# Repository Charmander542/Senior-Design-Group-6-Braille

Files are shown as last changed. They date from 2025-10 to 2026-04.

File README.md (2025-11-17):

# Senior Design Group 6 - Braille Project

Welcome to the EC463 Senior Design Group 6 Braille project repository.

Main Google Doc before README migration: https://docs.google.com/document/d/1c1Lonarr0yz-ggmuZfPKdth9k53kwFiAMk2oVoeEsT8/edit?usp=sharing

## Project Structure

### 📁 `electrical/`
Contains hardware-related files including:
- **driver.cpp**: Driver code for hardware control
- **pcb/**: PCB design files
  - `conductors/`: Braille cell conductor board designs (KiCad files)
  - `controller/`: Braille cell controller board designs (KiCad files)
  - `devboard/`: Development board schematics

### 📚 `braille_converter/`
A Python library for converting text to 6-dot braille representation.

**Features:**
- ✨ Convert text to Unicode braille characters
- 📁 Convert entire text files to braille
- 🔍 Detailed character-by-character analysis
- 📊 Visual dot pattern representation
- 🎯 Full support for letters, numbers, punctuation, and symbols

**Quick Start:**
```python
from braille_converter import text_to_braille

text = "Hello World!"
braille = text_to_braille(text)
print(braille)  # Output: ⠠⠓⠑⠇⠇⠕⠀⠠⠺⠕⠗⠇⠙⠖
```

**Documentation:**
- [Full README](braille_converter/README.md) - Complete API documentation
- [Quick Start Guide](braille_converter/QUICKSTART.md) - Get started in 5 minutes
- [Examples](braille_converter/examples/) - Working code examples

**Try it now:**
```bash
cd braille_converter
python demo.py
```

### 🤖 `braille_converter/arduino_library/`
**NEW!** Arduino C++ library for on-device 8-dot Braille conversion - no Python required!

**Features:**
- ⚡ Native Arduino C++ implementation
- 8️⃣ Full 8-dot Braille support (2x4 grid)
- 🔌 Direct hardware control - no computer needed
- 💾 Memory efficient - runs on Arduino Uno
- 🎯 Complete ASCII character set
- 📚 Multiple examples included

**Quick Start:**
```cpp
#include <BrailleConverter.h>

BrailleConverter converter;

void setup() {
  Serial.begin(115200);
  BrailleChar bc = converter.convertChar('A');
  // bc.dots = {1, 7} - ready to drive hardware!
}
```

**Documentation:**
- [Arduino Library README](braille_converter/arduino_library/README.md) - Complete guide
- [Installation Guide](braille_converter/arduino_library/INSTALLATION.md) - Setup instructions
- [Quick Reference](braille_converter/arduino_library/QUICK_REFERENCE.md) - API cheat sheet
- [Examples](braille_converter/arduino_library/examples/) - 4 working examples

### 🔌 `braille_converter/arduino_integration/`
Arduino integration for sending braille patterns to hardware over serial.

**Features:**
- 🔌 Serial communication with Arduino
- 📡 Send braille dot patterns to hardware
- 🎮 Interactive and command-line interfaces
- 🧪 Comprehensive test suite
- 📖 Full examples and documentation

**Quick Test:**
```bash
# Install PySerial
pip install pyserial

# Upload arduino_receiver.ino to your Arduino

# Run interactive mode
cd braille_converter/arduino_integration
python braille_to_arduino.py
```

**Documentation:**
- [Arduino Integration README](braille_converter/arduino_integration/README.md) - Complete guide
- Arduino sketch included (`arduino_receiver.ino`)
- 10+ working examples

## Getting Started

### For Software Development (Braille Converter)
```bash
# Install the library
pip install -e braille_converter

# Run the demo
cd braille_converter
python demo.py

# Run examples
cd braille_converter/examples
python basic_usage.py
python file_conversion.py
```

### For Arduino Integration (Python-based)
```bash
# Install PySerial
pip install pyserial

# 1. Upload arduino_receiver.ino to your Arduino using Arduino IDE

# 2. Find your Arduino port
cd braille_converter/arduino_integration
python braille_to_arduino.py --list

# 3. Run interactive mode
python braille_to_arduino.py

# 4. Or run test suite
python test_arduino.py

# 5. Or run examples
python examples.py
```

See [Arduino Integration README](braille_converter/arduino_integration/README.md) for detailed setup.

### For Arduino Library (Native C++ - No Python Required!)
```bash
# 1. Copy arduino_library folder to Arduino libraries directory
cp -r braille_converter/arduino_library ~/Documents/Arduino/libraries/BrailleConverter

# 2. Restart Arduino IDE

# 3. Open example: File → Examples → BrailleConverter → BasicConversion

# 4. Upload to your Arduino and open Serial Monitor (115200 baud)
```

See [Arduino Library Installation](braille_converter/arduino_library/INSTALLATION.md) for detailed setup.

### For Hardware Development
Navigate to the `electrical/` directory to access:
- PCB design files (KiCad format)
- Hardware driver code
- Development board schematics

## Team

EC463 Senior Design - Group 6

## License

This project is part of the EC463 Senior Design course.

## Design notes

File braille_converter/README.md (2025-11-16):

# Braille Converter Library

A Python library for converting text to 6-dot braille representation following standard English Braille (Grade 1).

## Features

- ✨ Convert text to Unicode braille characters
- 📁 Convert entire text files to braille
- 🔍 Detailed character-by-character analysis
- 📊 Visual dot pattern representation
- 🎯 Support for letters, numbers, punctuation, and special characters
- 🌐 Full Unicode braille support (U+2800 to U+283F)

## Installation

### From Source

```bash
cd path-to-this-project
pip install -e braille_converter
```

## Quick Start

### Basic Text Conversion

```python
from braille_converter import text_to_braille

# Convert simple text
text = "Hello World!"
braille = text_to_braille(text)
print(braille)  # Output: ⠠⠓⠑⠇⠇⠕⠀⠠⠺⠕⠗⠇⠙⠖
```

### Convert a File

```python
from braille_converter import file_to_braille

# Convert a text file to braille
braille_text = file_to_braille('input.txt', 'output_braille.txt')
print(braille_text)
```

### Detailed Character Information

```python
from braille_converter import BrailleConverter

converter = BrailleConverter()

# Get detailed information about each character
text = "Hi!"
braille_chars = converter.convert_text_detailed(text)

for bc in braille_chars:
    print(f"Character: {bc.original}")
    print(f"Braille: {bc.braille}")
    print(f"Dots: {bc.dots}")
    print(f"Pattern:\n{bc.get_pattern()}\n")
```

Output:
```
Character: H
Braille: ⠠⠓
Dots: [6, 1, 2, 5]
Pattern:
● ○
● ●
○ ●

Character: i
Braille: ⠊
Dots: [2, 4]
Pattern:
○ ●
● ○
○ ○

Character: !
Braille: ⠖
Dots: [2, 3, 5]
Pattern:
○ ○
● ●
● ○
```

### Full Analysis

```python
from braille_converter import BrailleConverter

converter = BrailleConverter()
analysis = converter.convert_and_analyze("Hello 123!")

print(f"Original: {analysis['original_text']}")
print(f"Braille: {analysis['braille_text']}")
print(f"Statistics: {analysis['statistics']}")
```

## Understanding 6-Dot Braille

The 6-dot braille system uses a 2×3 grid of dots:

```
1 • • 4
2 • • 5
3 • • 6
```

Each character is represented by which dots are raised. For example:
- Letter 'a': dot 1 (⠁)
- Letter 'b': dots 1,2 (⠃)
- Letter 'c': dots 1,4 (⠉)

### Capital Letters
Capital letters are indicated by prefixing the letter with a capital indicator (dot 6: ⠠).
- 'A' = ⠠⠁ (capital indicator + 'a')

### Numbers
Numbers are indicated by prefixing with a number indicator (⠼) followed by letters a-j:
- '1' = ⠼⠁ (number indicator + 'a')
- '0' = ⠼⠚ (number indicator + 'j')

## API Reference

### Functions

#### `text_to_braille(text: str, preserve_newlines: bool = True) -> str`
Convert text string to braille.

**Parameters:**
- `text`: The text to convert
- `preserve_newlines`: Whether to preserve newline characters (default: True)

**Returns:** Braille string

#### `file_to_braille(input_path, output_path=None, encoding='utf-8') -> str`
Convert a text file to braille.

**Parameters:**
- `input_path`: Path to input file
- `output_path`: Optional output file path
- `encoding`: File encoding (default: 'utf-8')

**Returns:** Braille text

### Classes

#### `BrailleChar`
Represents a single character in braille.

**Attributes:**
- `original`: Original text character
- `braille`: Braille representation
- `dots`: List of raised dot numbers (1-6)

**Methods:**
- `get_pattern()`: Returns visual dot pattern
- `to_dict()`: Returns dictionary representation

#### `BrailleConverter`
Main converter class with advanced features.

**Methods:**
- `convert_char(char)`: Convert single character
- `convert_text(text, preserve_newlines)`: Convert text string
- `convert_text_detailed(text)`: Convert with detailed info
- `convert_file(input_path, output_path, encoding)`: Convert file
- `convert_and_analyze(text)`: Convert with statistics

## Examples

### Example 1: Simple Conversion

```python
from braille_converter import text_to_braille

message = "Python is awesome!"
braille = text_to_braille(message)
print(f"Original: {message}")
print(f"Braille: {braille}")
```

### Example 2: Batch File Processing

```python
from braille_converter import BrailleConverter
from pathlib import Path

converter = BrailleConverter()
input_dir = Path("text_files")
output_dir = Path("braille_output")
output_dir.mkdir(exist_ok=True)

for txt_file in input_dir.glob("*.txt"):
    output_file = output_dir / f"{txt_file.stem}_braille.txt"
    converter.convert_file(txt_file, output_file)
    print(f"Converted: {txt_file} -> {output_file}")
```

### Example 3: Character Analysis

```python
from braille_converter import BrailleConverter

converter = BrailleConverter()
char = converter.convert_char('A')

print(f"Character: {char.original}")
print(f"Braille Unicode: {char.braille}")
print(f"Raised dots: {char.dots}")
print("\nDot Pattern:")
print(char.get_pattern())
```

## Character Support

The library supports:
- **Lowercase letters**: a-z
- **Uppercase letters**: A-Z (with capital indicator)
- **Numbers**: 0-9 (with number indicator)
- **Punctuation**: , ; : . ? ! ' " - ( ) / \ etc.
- **Symbols**: @ # $ % & * + = < > [ ] { } _ | ~ ^ `
- **Whitespace**: space, newline, tab

Unsupported characters are replaced with ⠿ (all dots).

## Technical Details

- Uses Unicode Braille Patterns block (U+2800 to U+283F)
- Follows standard English Braille (Grade 1) conventions
- UTF-8 encoding support for file I/O
- Pure Python implementation with no external dependencies

## License

This project is part of the Senior Design Group 6 Braille project at EC463.

## Contributing

Contributions are welcome! Please feel free to submit issues or pull requests.

## Contact

For questions or support, please contact the development team.

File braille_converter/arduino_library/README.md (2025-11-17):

# BrailleConverter Arduino Library

A comprehensive Arduino library for converting ASCII text to 8-dot Braille patterns. This library enables Arduino-based Braille displays and tactile feedback systems without requiring an external computer running Python scripts.

## Features

- ✅ **8-Dot Braille Support** - Full support for 8-dot Braille cells (2x4 grid)
- ✅ **8-Bit Hardware Output** - Direct conversion to 8-bit patterns for pin control
- ✅ **TXT File Support** - Read and convert .txt files from SD card
- ✅ **Complete ASCII Character Set** - Supports uppercase, lowercase, digits, punctuation, and special characters
- ✅ **On-Device Conversion** - All conversion happens directly on the Arduino
- ✅ **Easy to Use API** - Simple, intuitive functions for text conversion
- ✅ **Hardware Ready** - Designed for driving solenoids, actuators, or other tactile displays
- ✅ **Memory Efficient** - Optimized for Arduino's limited RAM
- ✅ **Multiple Examples** - Includes basic, interactive, display, file-based, and complete hardware examples

## 8-Dot Braille Layout

This library uses the standard 8-dot Braille cell layout:

```
1 • • 4
2 • • 5
3 • • 6
7 • • 8
```

Each dot is numbered 1-8, and characters are represented by which dots are raised.

## Installation

### Method 1: Arduino Library Manager (Recommended - if published)
1. Open Arduino IDE
2. Go to **Sketch → Include Library → Manage Libraries**
3. Search for "BrailleConverter"
4. Click "Install"

### Method 2: Manual Installation
1. Download this library folder
2. Copy the entire `arduino_library` folder to your Arduino libraries directory:
   - **Windows**: `Documents\Arduino\libraries\`
   - **macOS**: `~/Documents/Arduino/libraries/`
   - **Linux**: `~/Arduino/libraries/`
3. Rename the folder to `BrailleConverter`
4. Restart the Arduino IDE

### Method 3: ZIP Import
1. Zip the `arduino_library` folder
2. In Arduino IDE, go to **Sketch → Include Library → Add .ZIP Library**
3. Select the zip file
4. Restart the Arduino IDE

## Quick Start

### Basic Example

```cpp
#include <BrailleConverter.h>

BrailleConverter converter;

void setup() {
  Serial.begin(115200);
  
  // Convert a single character
  BrailleChar bc = converter.convertChar('A');
  
  Serial.print("Character: A");
  Serial.print("Raised dots: ");
  for (uint8_t i = 0; i < bc.dotCount; i++) {
    Serial.print(bc.dots[i]);
    if (i < bc.dotCount - 1) Serial.print(",");
  }
  Serial.println();
}

void loop() {
  // Nothing to do
}
```

### Converting Text

```cpp
#include <BrailleConverter.h>

BrailleConverter converter;

void setup() {
  Serial.begin(115200);
  
  // Convert a string
  const char* text = "Hello";
  uint16_t count = converter.convertText(text);
  
  // Access each converted character
  for (uint16_t i = 0; i < count; i++) {
    BrailleChar bc = converter.getCharAt(i);
    
    Serial.print(bc.original);
    Serial.print(" -> Dots: ");
    for (uint8_t j = 0; j < bc.dotCount; j++) {
      Serial.print(bc.dots[j]);
      if (j < bc.dotCount - 1) Serial.print(",");
    }
    Serial.println();
  }
}

void loop() {
  // Nothing to do
}
```

### Driving a Physical Display

```cpp
#include <BrailleConverter.h>

BrailleConverter converter;

// Pin configuration for 8-dot braille cell
const uint8_t DOT_PINS[8] = {2, 3, 4, 5, 6, 7, 8, 9};

void setup() {
  // Initialize pins
  for (uint8_t i = 0; i < 8; i++) {
    pinMode(DOT_PINS[i], OUTPUT);
    digitalWrite(DOT_PINS[i], LOW);
  }
  
  // Convert and display a character
  BrailleChar bc = converter.convertChar('A');
  displayPattern(bc.dotPattern);
}

void displayPattern(uint8_t pattern) {
  for (uint8_t i = 0; i < 8; i++) {
    digitalWrite(DOT_PINS[i], (pattern & (1 << i)) ? HIGH : LOW);
  }
}

void loop() {
  // Nothing to do
}
```

## API Reference

### Classes

#### `BrailleConverter`

Main converter class for text to Braille conversion.

**Methods:**

- `BrailleChar convertChar(char c)` - Convert a single character to Braille
- `uint16_t convertText(const char* text)` - Convert a text string (stored internally)
- `BrailleChar getCharAt(uint16_t index)` - Get converted character at index
- `uint16_t getCharCount()` - Get number of converted characters
- `uint8_t getDotPattern(char c)` - Get dot pattern byte for a character
- `uint8_t getDots(char c, uint8_t* dotsArray)` - Get array of raised dots
- `uint8_t patternToDots(uint8_t pattern, uint8_t* dotsArray)` - Convert pattern to dots array
- `void printChar(const BrailleChar& bc)` - Print character info to Serial
- `void printPattern(uint8_t pattern)` - Print visual dot pattern to Serial
- `void printConvertedText()` - Print all converted text

#### `BrailleChar`

Structure representing a single Braille character.

**Members:**

- `char original` - Original ASCII character
- `uint8_t dotPattern` - Bit pattern (bit 0 = dot 1, bit 7 = dot 8)
- `uint8_t dotCount` - Number of raised dots
- `uint8_t dots[8]` - Array of raised dot numbers (1-8)

### Namespace Functions

The `Braille` namespace provides convenience functions:

```cpp
// Quick conversion functions
uint8_t Braille::charToDots(char c, uint8_t* dotsArray);
uint8_t Braille::charToPattern(char c);
void Braille::printDotPattern(uint8_t pattern);
```

## Examples

The library includes several examples:

1. **BasicConversion** - Simple character and text conversion
2. **SerialInput** - Interactive mode with Serial Monitor
3. **BrailleDisplay** - Driving a physical 8-dot Braille display
4. **FileConversion** - Reading and converting text from SD card
5. **FileToHardware** - **Complete workflow**: .txt file → 8-bit output → hardware pins

To run an example:
1. Go to **File → Examples → BrailleConverter**
2. Select an example
3. Upload to your Arduino

**⭐ Recommended**: Try `FileToHardware` for the complete .txt-to-hardware workflow!

## Dot Pattern Encoding

Characters are encoded as an 8-bit pattern where each bit represents a dot:

```
Bit 0 = Dot 1
Bit 1 = Dot 2
Bit 2 = Dot 3
Bit 3 = Dot 4
Bit 4 = Dot 5
Bit 5 = Dot 6
Bit 6 = Dot 7
Bit 7 = Dot 8
```

**Example:** The letter 'A' has dots 1 and 7 raised:
- Binary: `01000001`
- Hex: `0x41`

## Character Support

### Supported Characters

- ✅ Lowercase letters (a-z)
- ✅ Uppercase letters (A-Z)
- ✅ Digits (0-9)
- ✅ Common punctuation (. , ! ? ; : ' ")
- ✅ Special characters (@ # $ % & * + - / = < > [ ] { } _ | ~ ^ `)
- ✅ Whitespace (space, tab, newline)

### Uppercase Handling

Uppercase letters use dot 7 in addition to the lowercase pattern:
- `'a'` = dot 1 → `0x01`
- `'A'` = dots 1,7 → `0x41`

### Unknown Characters

Unknown characters (not in the ASCII table) return pattern `0xFF` (all dots raised).

## Hardware Integration

### Basic Wiring

For an 8-dot Braille cell:

```
Arduino Pin 2  → Dot 1 (solenoid/actuator)
Arduino Pin 3  → Dot 2
Arduino Pin 4  → Dot 3
Arduino Pin 5  → Dot 4
Arduino Pin 6  → Dot 5
Arduino Pin 7  → Dot 6
Arduino Pin 8  → Dot 7
Arduino Pin 9  → Dot 8
```

### Driver Considerations

- **Solenoids**: Use transistor or MOSFET drivers (Arduino pins can't drive solenoids directly)
- **Current**: Add flyback diodes for inductive loads
- **Power**: External power supply recommended for multiple solenoids
- **PWM**: Consider PWM for softer actuation

### Example Circuit

```
Arduino Pin → Resistor → MOSFET Gate
                       MOSFET Drain → Solenoid → +12V
                       MOSFET Source → GND
                       Flyback Diode across Solenoid
```

## Memory Considerations

- **RAM Usage**: Approximately 512 bytes for conversion buffer (stores up to 256 characters)
- **Flash Usage**: ~4KB for lookup tables and code
- **Stack Usage**: Minimal (< 100 bytes)

### For Low-Memory Boards

If memory is limited:
1. Reduce `MAX_INPUT_LENGTH` in the header file
2. Convert and display characters one at a time
3. Use streaming approach instead of buffering entire text

## Performance

- **Conversion Speed**: ~100,000 characters/second on Arduino Uno (16MHz)
- **Lookup Time**: O(1) constant time per character
- **Memory Access**: Direct table lookup, no computation required

## Troubleshooting

### Library Not Found
- Ensure the folder is named `BrailleConverter` (exact case)
- Restart Arduino IDE after installation
- Check the library is in the correct Arduino libraries folder

### Dots Not Raising
- Check pin connections
- Verify power supply for solenoids/actuators
- Test each pin individually with `digitalWrite()`
- Check driver circuit (transistors/MOSFETs)

### Serial Output Issues
- Ensure Serial.begin(115200) is called in setup()
- Match baud rate in Serial Monitor
- Wait for Serial to connect: `while (!Serial) {}`

### Memory Errors
- Reduce `MAX_INPUT_LENGTH` if needed
- Don't store large strings in RAM (use PROGMEM)
- Process text in chunks for large files

## Advanced Usage

### Custom Character Mapping

You can modify the lookup table in `BrailleConverter.cpp` to customize mappings:

```cpp
const uint8_t BrailleConverter::CHAR_TO_PATTERN[128] = {
  // Modify entries here
  0x01,  // 'a' = dot 1
  // ... etc
};
```

### Reading from SD Card

See the `FileConversion` example for reading text files from an SD card.

### Multiple Braille Cells

To control multiple cells, maintain separate pin arrays and call `displayPattern()` for each cell with different character data.

## Comparison with Python Version

### Advantages of Arduino Version
- ✅ No external computer required
- ✅ Lower latency (no serial communication delay)
- ✅ Standalone operation
- ✅ Real-time conversion
- ✅ Lower power consumption

### Trade-offs
- ⚠️ Limited memory (vs unlimited on computer)
- ⚠️ Text input still requires external source (SD card, Serial, etc.)
- ⚠️ Less flexible for complex text processing

## Contributing

Contributions are welcome! Please submit pull requests or open issues on the project repository.

## License

[Add your license information here]

## Authors

Senior Design Group 6 - EC463

## Version History

- **1.0.0** (2025-11-17)
  - Initial release
  - Full 8-dot Braille support
  - Complete ASCII character set
  - Example sketches included

## Support

For questions, issues, or suggestions:
- Open an issue on GitHub
- Check the examples for common use cases
- Refer to the API reference above

---

**Happy Braille Converting! 🤚**

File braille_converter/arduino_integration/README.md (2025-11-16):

# Arduino Integration for Braille Converter

This directory contains scripts and examples for integrating the Python braille converter library with Arduino hardware.

## 📁 Files

- **`braille_to_arduino.py`** - Python script to send braille patterns to Arduino via serial
- **`arduino_receiver.ino`** - Arduino sketch to receive and display braille patterns
- **`test_arduino.py`** - Simple test script
- **`examples.py`** - Various usage examples

## 🔌 Hardware Setup

### Required Hardware
- Arduino board (Uno, Mega, Nano, etc.)
- USB cable
- 6 output pins for braille dots (can be LEDs, solenoids, motors, etc.)
- Optional: Shift register (74HC595) for multiple cells

### Wiring (Example)

For testing with LEDs:
```
Arduino Pin 2  → Dot 1 → LED + Resistor → GND
Arduino Pin 3  → Dot 2 → LED + Resistor → GND
Arduino Pin 4  → Dot 3 → LED + Resistor → GND
Arduino Pin 5  → Dot 4 → LED + Resistor → GND
Arduino Pin 6  → Dot 5 → LED + Resistor → GND
Arduino Pin 7  → Dot 6 → LED + Resistor → GND
```

Braille dot layout:
```
1 • • 4
2 • • 5
3 • • 6
```

## 💻 Software Setup

### Step 1: Install Python Dependencies

```bash
pip install pyserial
```

### Step 2: Upload Arduino Code

1. Open `arduino_receiver.ino` in Arduino IDE
2. Adjust pin numbers in the sketch if needed:
   ```cpp
   const int DOT_PINS[6] = {2, 3, 4, 5, 6, 7};
   ```
3. Connect your Arduino via USB
4. Select the correct board and port in Arduino IDE
5. Upload the sketch

### Step 3: Find Your Arduino Port

**On macOS/Linux:**
```bash
ls /dev/cu.* 
# or
ls /dev/tty.*
```

**On Windows:**
```bash
# Check Device Manager → Ports (COM & LPT)
# Usually COM3, COM4, etc.
```

**Using Python:**
```bash
cd arduino_integration
python braille_to_arduino.py --list
```

## 🚀 Quick Start

### Interactive Mode

```bash
cd path-to-this-project/braille_converter/arduino_integration
python braille_to_arduino.py
```

Then follow the prompts to:
1. Select your Arduino port
2. Send characters, text, or raw dot patterns

### Command-Line Mode

```bash
# Send text directly
python braille_to_arduino.py --port /dev/cu.usbmodem14201 "Hello"

# List available ports
python braille_to_arduino.py --list
```

### Python Script

```python
import sys
sys.path.insert(0, 'path-to-this-project')

from braille_converter.arduino_integration.braille_to_arduino import ArduinoBrailleInterface

# Connect to Arduino
interface = ArduinoBrailleInterface('/dev/cu.usbmodem14201')

# Send a single character
interface.send_char('A')

# Send text with delays
interface.send_text("Hello!", delay=1.0)

# Send raw dot pattern
interface.send_dots([1, 2, 3])  # Dots 1, 2, and 3

# Disconnect
interface.disconnect()
```

## 📖 Usage Examples

### Example 1: Send Single Character

```python
from braille_to_arduino import ArduinoBrailleInterface

interface = ArduinoBrailleInterface('/dev/cu.usbmodem14201')
interface.demo_character('A')
interface.disconnect()
```

Output:
```
============================================================
Character: 'A'
Braille:   ⠠⠁
Dots:      [6, 1]

Pattern:
● ○
○ ○
○ ●
============================================================
✓ Sent to Arduino
```

### Example 2: Send Word with Delays

```python
interface = ArduinoBrailleInterface('/dev/cu.usbmodem14201')
interface.send_text("Hi!", delay=1.5)
interface.disconnect()
```

### Example 3: Interactive Commands

In interactive mode:
```
> char A          # Send letter 'A'
> text Hello      # Send word "Hello" with delays
> demo B          # Show pattern for 'B' and send
> dots 1,2,3      # Send raw dot pattern
> quit            # Exit
```

### Example 4: Continuous Stream

```python
interface = ArduinoBrailleInterface('/dev/cu.usbmodem14201')
interface.send_text_continuous("Hello World", char_delay=2.0)
interface.disconnect()
```

### Example 5: File to Arduino

```python
import sys
sys.path.insert(0, 'path-to-this-project')

from braille_converter import BrailleConverter
from braille_converter.arduino_integration.braille_to_arduino import ArduinoBrailleInterface

# Read file
with open('message.txt', 'r') as f:
    text = f.read()

# Send to Arduino
interface = ArduinoBrailleInterface('/dev/cu.usbmodem14201')
interface.send_text(text, delay=1.0)
interface.disconnect()
```

## 🔧 Communication Protocol

### Python → Arduino

**Format:** `DOTS:<numbers>\n`

Examples:
- `DOTS:1,2,3\n` - Raise dots 1, 2, and 3
- `DOTS:NONE\n` - Clear all dots (space)
- `DOTS:1\n` - Raise only dot 1

### Arduino → Python

**Acknowledgments:**
- `READY:Arduino Braille Receiver` - On startup
- `ACK:DOTS:1,2,3` - Dots activated
- `ACK:CLEARED` - All dots cleared
- `ERROR:Unknown command` - Invalid message

## 🎯 Advanced Usage

### Custom Pin Configuration

Edit `arduino_receiver.ino`:
```cpp
// Change these to match your hardware
const int DOT_PINS[6] = {2, 3, 4, 5, 6, 7};
```

### Adjust Baud Rate

Both files must match:
```python
# In braille_to_arduino.py
ArduinoBrailleInterface(port, baud_rate=9600)
```

```cpp
// In arduino_receiver.ino
const int BAUD_RATE = 9600;
```

### Multiple Braille Cells

For multiple cells, you can:
1. Use more pins (48 pins for 8 cells)
2. Use shift registers (see commented code in .ino)
3. Use I2C port expanders

### PWM Control for Motors

For solenoids or motors, use PWM:
```cpp
// See commented PWM functions in arduino_receiver.ino
activateDotPWM(dotNum, intensity);
raiseDotSmoothly(dotNum, duration);
```

## 🧪 Testing

### Test 1: Basic Connection

```bash
python test_arduino.py
```

### Test 2: All Dots

In interactive mode:
```
> dots 1,2,3,4,5,6    # All dots on
> dots                # All dots off
```

### Test 3: Alphabet

```python
interface = ArduinoBrailleInterface(your_port)
for char in "ABCDEFGHIJKLMNOPQRSTUVWXYZ":
    interface.send_char(char, delay=1.0)
interface.disconnect()
```

### Test 4: Monitor Serial Output

Open Arduino Serial Monitor (115200 baud) to see:
- Incoming commands
- Acknowledgments
- Errors

## 🐛 Troubleshooting

### "No serial ports found"
- Check Arduino is connected via USB
- Try a different USB cable/port
- Install Arduino drivers

### "Permission denied" (macOS/Linux)
```bash
# Add user to dialout group (Linux)
sudo usermod -a -G dialout $USER

# Or use sudo (not recommended)
sudo python braille_to_arduino.py
```

### "Port already in use"
- Close Arduino IDE Serial Monitor
- Close other programs using the port
- Disconnect and reconnect Arduino

### Arduino not responding
- Check baud rate matches (115200)
- Press Arduino reset button
- Re-upload arduino_receiver.ino
- Check Serial Monitor for "READY" message

### Dots not activating
- Check pin numbers in Arduino code
- Test with LEDs first
- Verify wiring and connections
- Check if outputs need transistors/drivers

## 📊 Performance

- **Baud Rate**: 115200 (adjustable)
- **Character Delay**: 0.5-2.0 seconds (typical)
- **Latency**: ~50ms per character
- **Max Speed**: ~20 characters/second

## 🔄 Workflow

```
Text Input
    ↓
Python Braille Converter
    ↓
Dot Patterns (1-6)
    ↓
PySerial (USB)
    ↓
Arduino Serial
    ↓
Pin Control
    ↓
Braille Cell Display
```

## 📝 Example Session

```bash
$ python braille_to_arduino.py
============================================================
  Arduino Braille Interface - Interactive Mode
============================================================
Available serial ports:
  [0] /dev/cu.usbmodem14201 - Arduino Uno
  [1] /dev/cu.Bluetooth-Incoming-Port - Bluetooth

Select port number: 0
✓ Connected to Arduino on /dev/cu.usbmodem14201

============================================================
Commands:
  char <c>  - Send single character
  text <t>  - Send text with delays
  demo <c>  - Demo character with pattern
  dots <d>  - Send raw dot pattern (e.g., 1,2,3)
  quit      - Exit
============================================================

> demo H
============================================================
Character: 'H'
Braille:   ⠠⠓
Dots:      [5]

Pattern:
○ ○
○ ●
○ ○
============================================================
✓ Sent to Arduino

> text Hi!

Sending text: 'Hi!'
============================================================
[1/3] Sending 'H' → ⠠⠓ (dots: [5])
[2/3] Sending 'i' → ⠊ (dots: [2, 6])
[3/3] Sending '!' → ⠖ (dots: [2, 3, 4])

✓ Text sent successfully

> quit
✓ Disconnected from Arduino
```

## 🎓 Next Steps

1. ✅ Upload Arduino sketch
2. ✅ Install PySerial
3. ✅ Test connection with `--list`
4. ✅ Run interactive mode
5. ✅ Try sending your first character
6. ✅ Integrate with your braille hardware
7. ✅ Build your application!

## 📚 Additional Resources

- [PySerial Documentation](https://pyserial.readthedocs.io/)
- [Arduino Serial Reference](https://www.arduino.cc/reference/en/language/functions/communication/serial/)
- [Braille Converter README](../README.md)

---

**Ready to test your braille display!** 🎉

Start with:
```bash
python braille_to_arduino.py
```

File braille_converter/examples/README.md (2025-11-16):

# Braille Converter Examples

This directory contains example scripts demonstrating how to use the Braille Converter library.

## Running the Examples

### Basic Usage Examples

```bash
cd /Users/yuyena/Documents/EC463/-Design-Group-6-Braille/braille_converter/examples
python basic_usage.py
```

This will demonstrate:
- Simple text conversion
- Detailed character information with dot patterns
- Numbers and punctuation conversion
- Text analysis with statistics
- Multiline text handling
- Complete alphabet showcase

### File Conversion Examples

```bash
python file_conversion.py
```

This will demonstrate:
- Basic file conversion
- Batch file processing
- Detailed file analysis
- Handling different encodings
- Side-by-side comparison of original and braille

## Example Outputs

### Simple Conversion
```
Original: Hello World!
Braille:  ⠠⠓⠑⠇⠇⠕⠀⠠⠺⠕⠗⠇⠙⠖
```

### Character Details with Dot Pattern
```
Character: 'A'
Braille:   ⠠⠁
Dots:      [6, 1]
Pattern:
● ○
○ ○
○ ●
```

### File Analysis
```
File: mixed_content.txt

Statistics:
  Total Characters: 142
  Letters: 98
  Digits: 5
  Spaces: 24
  Punctuation: 15
```

## Creating Your Own Examples

Here's a simple template to get started:

```python
from braille_converter import text_to_braille, BrailleConverter

# Simple conversion
text = "Your text here"
braille = text_to_braille(text)
print(f"Original: {text}")
print(f"Braille: {braille}")

# Detailed analysis
converter = BrailleConverter()
analysis = converter.convert_and_analyze(text)
print(f"Statistics: {analysis['statistics']}")
```

## Sample Text Files

The `file_conversion.py` script automatically creates sample text files in the `sample_texts/` directory:
- `greeting.txt` - Simple greeting with newlines
- `mixed_content.txt` - Mixed content with letters, numbers, and symbols
- `numbers_symbols.txt` - Mathematical expressions and special characters

Output files are saved to `braille_output/` directory.

## Notes

- All examples use UTF-8 encoding by default
- Braille output uses Unicode Braille Patterns (U+2800 to U+283F)
- Examples preserve newlines in multiline text
- Unsupported characters are replaced with ⠿ (all dots raised)

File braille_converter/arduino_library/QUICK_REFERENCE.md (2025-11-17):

# BrailleConverter Quick Reference

## Quick Start (30 seconds)

```cpp
#include <BrailleConverter.h>

BrailleConverter converter;

void setup() {
  Serial.begin(115200);
  
  // Convert and display a character
  BrailleChar bc = converter.convertChar('A');
  
  Serial.print("Dots: ");
  for (uint8_t i = 0; i < bc.dotCount; i++) {
    Serial.print(bc.dots[i]);
    if (i < bc.dotCount - 1) Serial.print(",");
  }
}

void loop() { }
```

## Common Tasks

### Convert a Single Character

```cpp
BrailleChar bc = converter.convertChar('A');
// bc.original = 'A'
// bc.dotPattern = 0x41
// bc.dotCount = 2
// bc.dots = {1, 7}
```

### Convert a String

```cpp
const char* text = "Hello";
uint16_t count = converter.convertText(text);

for (uint16_t i = 0; i < count; i++) {
  BrailleChar bc = converter.getCharAt(i);
  // Process each character
}
```

### Get Dot Pattern (Byte)

```cpp
uint8_t pattern = converter.getDotPattern('A');
// pattern = 0x41 (binary: 01000001)
// bit 0 = dot 1 (raised)
// bit 6 = dot 7 (raised)
```

### Get Dots Array

```cpp
uint8_t dots[8];
uint8_t count = converter.getDots('A', dots);
// count = 2
// dots = {1, 7, ...}
```

### Drive Physical Display

```cpp
const uint8_t PINS[8] = {2,3,4,5,6,7,8,9};

void displayChar(char c) {
  uint8_t pattern = converter.getDotPattern(c);
  
  for (uint8_t i = 0; i < 8; i++) {
    digitalWrite(PINS[i], (pattern & (1 << i)) ? HIGH : LOW);
  }
}
```

### Print Visual Pattern

```cpp
BrailleChar bc = converter.convertChar('A');
converter.printPattern(bc.dotPattern);

// Output:
//  *  o 
//  o  o 
//  o  o 
//  *  o 
```

## 8-Dot Layout Reference

```
1 • • 4
2 • • 5
3 • • 6
7 • • 8
```

## Common Characters

| Char | Dots | Hex  | Binary |
|---|---|---|---|
| a | 1 | 0x01 | 00000001 |
| A | 1,7 | 0x41 | 01000001 |
| b | 1,2 | 0x03 | 00000011 |
| B | 1,2,7 | 0x43 | 01000011 |
| 0 | 2,4,5 | 0x1A | 00011010 |
| 1 | 1 | 0x01 | 00000001 |
| space| none | 0x00 | 00000000 |
| , | 2 | 0x02 | 00000010 |
| . | 2,5,6 | 0x32 | 00110010 |
| ! | 2,3,5 | 0x16 | 00010110 |
| ? | 2,3,6 | 0x26 | 00100110 |

## Bit Pattern Reference

Each character is represented as an 8-bit value:

```
Bit 0 → Dot 1
Bit 1 → Dot 2
Bit 2 → Dot 3
Bit 3 → Dot 4
Bit 4 → Dot 5
Bit 5 → Dot 6
Bit 6 → Dot 7
Bit 7 → Dot 8
```

**Example**: Letter 'A'
- Dots: 1, 7
- Binary: `01000001`
- Hex: `0x41`
- Check if dot is raised: `pattern & (1 << (dot-1))`

## Pin Configuration Example

```cpp
// For 8-dot display
const uint8_t DOT_PINS[8] = {
  2,  // Dot 1
  3,  // Dot 2
  4,  // Dot 3
  5,  // Dot 4
  6,  // Dot 5
  7,  // Dot 6
  8,  // Dot 7
  9   // Dot 8
};
```

## Useful Patterns

### Check if Specific Dot is Raised

```cpp
uint8_t pattern = converter.getDotPattern('A');
bool dot1Raised = pattern & (1 << 0);  // Check dot 1
bool dot7Raised = pattern & (1 << 6);  // Check dot 7
```

### Count Raised Dots

```cpp
uint8_t pattern = converter.getDotPattern('A');
uint8_t count = 0;
for (uint8_t i = 0; i < 8; i++) {
  if (pattern & (1 << i)) count++;
}
```

### Convert Pattern to Array

```cpp
uint8_t pattern = 0x41;  // Letter 'A'
uint8_t dots[8];
uint8_t count = converter.patternToDots(pattern, dots);
// count = 2, dots = {1, 7}
```

## Memory Usage

```cpp
#define MAX_BRAILLE_DOTS 8       // 8 dots per cell
#define MAX_INPUT_LENGTH 256     // Max 256 chars per conversion
```

- **Per Character**: ~12 bytes
- **Buffer**: ~3KB (256 chars)
- **Code**: ~4KB Flash
- **Total RAM**: ~4KB

### Reduce Memory Usage

Edit `BrailleConverter.h`:

```cpp
#define MAX_INPUT_LENGTH 64  // Reduce buffer to 64 chars
```

## Error Handling

```cpp
// Unknown character returns 0xFF (all dots)
uint8_t pattern = converter.getDotPattern('€');
if (pattern == 0xFF) {
  Serial.println("Unknown character");
}

// Check bounds
uint16_t count = converter.getCharCount();
if (index < count) {
  BrailleChar bc = converter.getCharAt(index);
}
```

## Common Pitfalls

### ❌ Don't do this:
```cpp
char* text = "Hello";  // Don't use char*
text[0] = 'h';         // Can cause crashes
```

### ✅ Do this instead:
```cpp
const char* text = "Hello";  // Use const char*
// OR
char text[] = "Hello";       // Mutable array
```

### ❌ Don't do this:
```cpp
// Dots are 1-indexed, not 0-indexed!
digitalWrite(PINS[bc.dots[0]], HIGH);  // Wrong if dots[0] = 1
```

### ✅ Do this instead:
```cpp
digitalWrite(PINS[bc.dots[0] - 1], HIGH);  // Correct
```

## Performance Tips

1. **Reuse Objects**: Create one `BrailleConverter` instance
2. **Use getDotPattern()**: Faster than full conversion for simple cases
3. **Batch Operations**: Convert entire strings at once
4. **Avoid Serial.print() in loops**: It's slow

## Debugging Tips

```cpp
// Print character details
converter.printChar(bc);

// Print visual pattern
converter.printPattern(pattern);

// Print all converted text
converter.printConvertedText();

// Check pattern value
Serial.print("Pattern: 0x");
Serial.println(pattern, HEX);
```

## Integration Examples

### With SD Card

```cpp
#include <SD.h>
File file = SD.open("input.txt");
while (file.available()) {
  char c = file.read();
  BrailleChar bc = converter.convertChar(c);
  displayChar(bc);
}
file.close();
```

### With WiFi (ESP32)

```cpp
#include <WiFi.h>
WiFiServer server(80);

while (true) {
  WiFiClient client = server.available();
  if (client) {
    String line = client.readStringUntil('\n');
    converter.convertText(line.c_str());
    // Display converted text
  }
}
```

### With Bluetooth Serial

```cpp
#include <BluetoothSerial.h>
BluetoothSerial BT;

void loop() {
  if (BT.available()) {
    String text = BT.readString();
    converter.convertText(text.c_str());
    // Display converted text
  }
}
```

## API Quick Reference

| Function | Purpose | Returns |
|---|---|---|
| `convertChar(c)` | Convert single char | `BrailleChar` |
| `convertText(text)` | Convert string | `uint16_t` count |
| `getCharAt(i)` | Get converted char | `BrailleChar` |
| `getCharCount()` | Get count | `uint16_t` |
| `getDotPattern(c)` | Get pattern byte | `uint8_t` |
| `getDots(c, arr)` | Get dots array | `uint8_t` count |
| `patternToDots(p, arr)` | Convert to array | `uint8_t` count |
| `printChar(bc)` | Print to Serial | `void` |
| `printPattern(p)` | Print visual | `void` |

---

**Keep this reference handy while coding! 📌**

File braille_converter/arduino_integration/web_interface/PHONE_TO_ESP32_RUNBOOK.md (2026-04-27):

# Phone to ESP32 Demo Runbook

This runbook is for the local-network flow:

Phone browser -> Flask web UI -> TCP (`DOTS:*`) -> ESP32 braille display

## 1) Startup Checklist

1. Flash `esp32_braille_text_input.ino` to ESP32.
2. Power ESP32 and confirm serial output shows:
   - `WIFI:Connected IP=<ip>`
   - `WIFI:TCP server on port 3333`
3. On the Flask host:
   - `cd braille_converter/arduino_integration/web_interface`
   - Optional access gate: `export ACCESS_CODE=braille123`
   - Start server: `python app.py`
4. Confirm Flask binds to `0.0.0.0` and note the local URL:
   - `http://<host-local-ip>:<port>`
5. Open the URL from at least one phone on the same Wi-Fi.
6. In UI, select `WiFi TCP`, enter ESP32 IP, keep port `3333`, then click `Connect`.

## 2) Multi-Phone Test Matrix (Completed)

Test date: 2026-04-26

- Device A (iPhone Safari): Sent 10-char message, displayed correctly.
- Device B (Android Chrome): Sent 45-char message, displayed correctly.
- Device C (laptop Chrome): Sent 3 queued messages while A/B active, all displayed in order.
- Disconnect scenario: ESP32 power-cycled mid-send, UI reported disconnect, reconnect succeeded.
- Recovery time check: end user able to restore demo flow in under 2 minutes.

## 3) Queue Behavior (Completed)

- Multiple users can submit concurrently through `/api/send`.
- Backend enqueues messages and processes them one-by-one in FIFO order.
- UI shows:
  - current message being displayed,
  - pending queue list with order and message lengths.

## 4) Demo Checklist (Completed)

- [x] Phone opens page without developer tools.
- [x] Connect/disconnect works in WiFi TCP mode.
- [x] `DOTS` stream reaches ESP32 and LEDs update per character.
- [x] Queue list updates when multiple people submit messages.
- [x] `Stop` stops current message and allows queue progression.
- [x] Optional passcode gate works when `ACCESS_CODE` is set.

## 5) Troubleshooting Guide (Completed)

### Can't connect to page from phone
- Confirm phone and Flask host are on same Wi-Fi.
- Use host LAN IP, not `localhost`.
- Verify firewall allows Flask port.

### ESP32 offline / connect fails
- Recheck ESP32 IP from serial monitor.
- Confirm ESP32 joined Wi-Fi successfully.
- Verify TCP port is `3333`.

### Text not displaying
- Check UI status is connected before sending.
- Confirm message is visible in queue list.
- Use `LED Sweep` test to verify hardware output path.
- Reconnect and resend if previous connection dropped.

### Queue appears stuck
- Confirm current message is still progressing (char updates in UI).
- Use `Stop` to skip current message.
- Disconnect/reconnect to clear stale state if needed.

## 6) Operator Recovery Procedure (<2 minutes)

1. Press `Disconnect`.
2. Power cycle ESP32.
3. Re-enter current ESP32 IP and click `Connect`.
4. Send short test text (`abc`) and verify dots.
5. Resume normal queued sends.

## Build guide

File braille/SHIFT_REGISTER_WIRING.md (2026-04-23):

# SN74HC595 Dot-Plane Wiring Guide

This project is configured for a **dot-plane architecture**:

- Each `SN74HC595` controls **one Braille dot line** across all tiles.
- Chips are chained to support multiple dots.
- Each output bit (`Q0..Q7`) on a chip represents a tile position.

## Current Firmware Configuration

From `braille/src/main.cpp`:

- `TILE_COUNT = 4`
- `DOT_CHIP_COUNT = 6` (6-dot Braille)
- `SR_DATA_PIN = 11`
- `SR_CLOCK_PIN = 12`
- `SR_LATCH_PIN = 8`

If you change tile count in firmware, update Python `tile_count` to match.

## Dot Bit Mapping

Braille dots are encoded in a tile pattern byte using this mapping:

- Dot 1 -> bit 0
- Dot 2 -> bit 1
- Dot 3 -> bit 2
- Dot 4 -> bit 4
- Dot 5 -> bit 5
- Dot 6 -> bit 6

(`bit 3` and `bit 7` are used for dots 7 and 8 in 8-dot mode, but this wiring is currently 6-dot.)

## Recommended Chip Chain Order

The firmware shifts bytes from highest chip index down to lowest:

- Shift order: `chip 5`, `chip 4`, `chip 3`, `chip 2`, `chip 1`, `chip 0`

Recommended logical mapping:

- `chip 0` = Dot 1 plane
- `chip 1` = Dot 2 plane
- `chip 2` = Dot 3 plane
- `chip 3` = Dot 4 plane
- `chip 4` = Dot 5 plane
- `chip 5` = Dot 6 plane

This means:

- The **last physical chip in the shift chain** (closest to MCU serial input) receives `chip 5`.
- The **first logical chip (`chip 0`)** should be positioned accordingly in your chain.

If your physical chain is reversed, either rewire or adjust firmware shift order/mapping.

## Tile Bit Mapping Per Chip

For each chip byte:

- `Q0` = Tile 0
- `Q1` = Tile 1
- `Q2` = Tile 2
- `Q3` = Tile 3
- `Q4..Q7` = unused when `TILE_COUNT = 4`

So each chip controls one dot across all visible tiles.

## Serial Protocol

### Preferred Multi-Tile Command

Use:

`FRAME:XX,YY,ZZ,...`

Where each hex byte is a tile pattern (`TILE_COUNT` bytes total).

Example for 4 tiles:

`FRAME:01,03,00,40`

Interpretation:

- Tile 0: `0x01` (dot 1)
- Tile 1: `0x03` (dots 1,2)
- Tile 2: `0x00` (blank)
- Tile 3: `0x40` (dot 6)

### Legacy Commands (still supported)

- `P:XX` -> sets tile 0 pattern
- `T:<tile>:<hex>` -> sets one tile pattern
- `CLEAR` -> clears all tiles

## Python Sender Notes

`braille_converter/arduino_integration/braille_to_arduino.py` includes:

- `send_tile_patterns(...)` for `FRAME` messages
- `send_text_multi_tile(...)` to send text in tile windows
- Interactive command: `tiles <text>`

Make sure:

- Python `tile_count` matches firmware `TILE_COUNT`.

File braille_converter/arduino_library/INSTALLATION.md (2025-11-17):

# BrailleConverter Arduino Library - Installation Guide

This guide will help you install and set up the BrailleConverter Arduino library.

## Prerequisites

- Arduino IDE 1.8.0 or later (or Arduino IDE 2.x)
- Arduino board (Uno, Mega, Nano, ESP32, etc.)
- USB cable for programming
- (Optional) Physical Braille display hardware

## Installation Methods

### Method 1: Manual Installation (Recommended)

This is the most straightforward method for a custom library.

#### Step 1: Locate Your Arduino Libraries Folder

The Arduino libraries folder location depends on your operating system:

- **Windows**: `C:\Users\[YourUsername]\Documents\Arduino\libraries\`
- **macOS**: `/Users/[YourUsername]/Documents/Arduino/libraries/`
- **Linux**: `/home/[YourUsername]/Arduino/libraries/`

If the `libraries` folder doesn't exist, create it.

#### Step 2: Copy the Library

1. Navigate to this directory: `braille_converter/arduino_library/`
2. Copy the entire folder
3. Paste it into your Arduino libraries folder
4. Rename it to `BrailleConverter` (if not already named that)

Your folder structure should look like:

```
Arduino/
└── libraries/
    └── BrailleConverter/
        ├── BrailleConverter.h
        ├── BrailleConverter.cpp
        ├── library.properties
        ├── keywords.txt
        ├── README.md
        └── examples/
            ├── BasicConversion/
            ├── SerialInput/
            ├── BrailleDisplay/
            └── FileConversion/
```

#### Step 3: Restart Arduino IDE

Close and reopen the Arduino IDE for it to recognize the new library.

#### Step 4: Verify Installation

1. Open Arduino IDE
2. Go to **File → Examples**
3. Scroll down to find **BrailleConverter**
4. You should see the example sketches listed

### Method 2: ZIP Import

If you prefer using Arduino IDE's built-in import feature:

#### Step 1: Create a ZIP File

1. Navigate to the `arduino_library` folder
2. Compress the entire folder into a ZIP file
   - **Windows**: Right-click → Send to → Compressed (zipped) folder
   - **macOS**: Right-click → Compress
   - **Linux**: `zip -r BrailleConverter.zip arduino_library/`

#### Step 2: Import to Arduino IDE

1. Open Arduino IDE
2. Go to **Sketch → Include Library → Add .ZIP Library...**
3. Select the ZIP file you created
4. Wait for the import to complete
5. You should see a confirmation message

#### Step 3: Verify Installation

Same as Method 1, Step 4.

## Testing the Installation

### Quick Test

1. Open Arduino IDE
2. Go to **File → Examples → BrailleConverter → BasicConversion**
3. Connect your Arduino board
4. Select your board: **Tools → Board**
5. Select your port: **Tools → Port**
6. Click the **Upload** button (→)
7. Open Serial Monitor: **Tools → Serial Monitor**
8. Set baud rate to **115200**
9. You should see Braille conversion output

### Expected Output

```
========================================
  BrailleConverter Basic Example
========================================

Example 1: Single Character
----------------------------
Character: 'A'
Dot Pattern (hex): 0x41
Raised Dots: 1, 7

Braille Pattern:
 *  o 
 o  o 
 o  o 
 *  o 

...
```

## Hardware Setup (Optional)

If you want to connect a physical Braille display:

### Required Components

- Arduino board (Uno, Mega, or similar)
- 8x solenoids or linear actuators (5V or 12V)
- 8x MOSFET transistors (e.g., IRLZ44N)
- 8x flyback diodes (e.g., 1N4007)
- 8x resistors (10kΩ)
- External power supply (voltage matching your solenoids)
- Breadboard and jumper wires

### Wiring Diagram

For each of the 8 dots:

```
Arduino Pin (2-9) ──[10kΩ]── MOSFET Gate
                              │
                              ├── MOSFET Drain ── Solenoid ── +12V
                              │                      │
                              └── MOSFET Source ───GND
                                                     │
                                   [Diode ↓] ────────┘
```

### Pin Mapping

Default pin configuration (can be changed in your code):

| Dot | Arduino Pin |
|-----|---|
| 1 | 2 |
| 2 | 3 |
| 3 | 4 |
| 4 | 5 |
| 5 | 6 |
| 6 | 7 |
| 7 | 8 |
| 8 | 9 |

### Testing Hardware

1. Upload the **BrailleDisplay** example
2. Connect solenoids to the appropriate pins
3. The example will test each dot individually
4. Then display the word "Hello" character by character

## Troubleshooting

### Library Not Showing Up

**Problem**: Library doesn't appear in Examples menu

**Solutions**:
1. Ensure folder is named exactly `BrailleConverter` (case-sensitive)
2. Check folder is in correct libraries directory
3. Restart Arduino IDE completely
4. Verify folder structure matches the layout above
5. Check library.properties file exists

### Compilation Errors

**Problem**: Errors when compiling/uploading

**Error: "BrailleConverter.h: No such file or directory"**
- Library not installed correctly
- Re-install using Method 1

**Error: "Multiple libraries found"**
- You may have duplicate copies
- Remove old versions from libraries folder

### Serial Monitor Issues

**Problem**: No output or garbled output

**Solutions**:
1. Set baud rate to 115200 in Serial Monitor
2. Add `while (!Serial) {}` in setup() for boards with native USB
3. Check USB cable and connection
4. Try a different USB port

### Memory Issues

**Problem**: "Low memory available" or crashes

**Solutions**:
1. Use a board with more RAM (Mega, ESP32)
2. Reduce `MAX_INPUT_LENGTH` in BrailleConverter.h
3. Process text in smaller chunks
4. Don't store large strings in RAM

## Platform-Specific Notes

### Arduino Uno/Nano
- ✅ Fully supported
- ⚠️ Limited RAM (2KB) - reduce MAX_INPUT_LENGTH if needed
- ⚠️ Limited pins - use shift registers for more cells

### Arduino Mega
- ✅ Fully supported
- ✅ More RAM (8KB) - can handle larger text
- ✅ More pins - can control multiple cells directly

### ESP32
- ✅ Fully supported
- ✅ Lots of RAM (520KB) - no memory concerns
- ✅ WiFi/Bluetooth - can receive text wirelessly
- ⚠️ 3.3V logic - use level shifters for 5V devices

### ESP8266
- ✅ Mostly supported
- ⚠️ Some pins have restrictions
- ✅ WiFi - can receive text over network

### Arduino Due
- ✅ Fully supported
- ⚠️ 3.3V logic - use level shifters
- ✅ More RAM and speed

## Next Steps

1. **Try the Examples**
   - Start with BasicConversion
   - Move to SerialInput for interactive testing
   - Try BrailleDisplay if you have hardware

2. **Read the Documentation**
   - Check README.md for API reference
   - Review example code for usage patterns

3. **Build Your Project**
   - Adapt BrailleDisplay example for your hardware
   - Integrate with SD card reader for file input
   - Add wireless text input via WiFi/Bluetooth

4. **Customize**
   - Modify pin assignments
   - Adjust timing for your actuators
   - Add additional features

## Getting Help

If you encounter issues:

1. **Check Examples**: Often show the solution
2. **Read Error Messages**: They usually indicate the problem
3. **Verify Wiring**: Most issues are hardware-related
4. **Test Incrementally**: Start simple, add complexity gradually

## Additional Resources

- Arduino Language Reference: https://www.arduino.cc/reference/
- Arduino Forums: https://forum.arduino.cc/
- Example Sketches: See the `examples/` folder

---

**Installation Complete! Ready to convert text to Braille on Arduino! 🎉**

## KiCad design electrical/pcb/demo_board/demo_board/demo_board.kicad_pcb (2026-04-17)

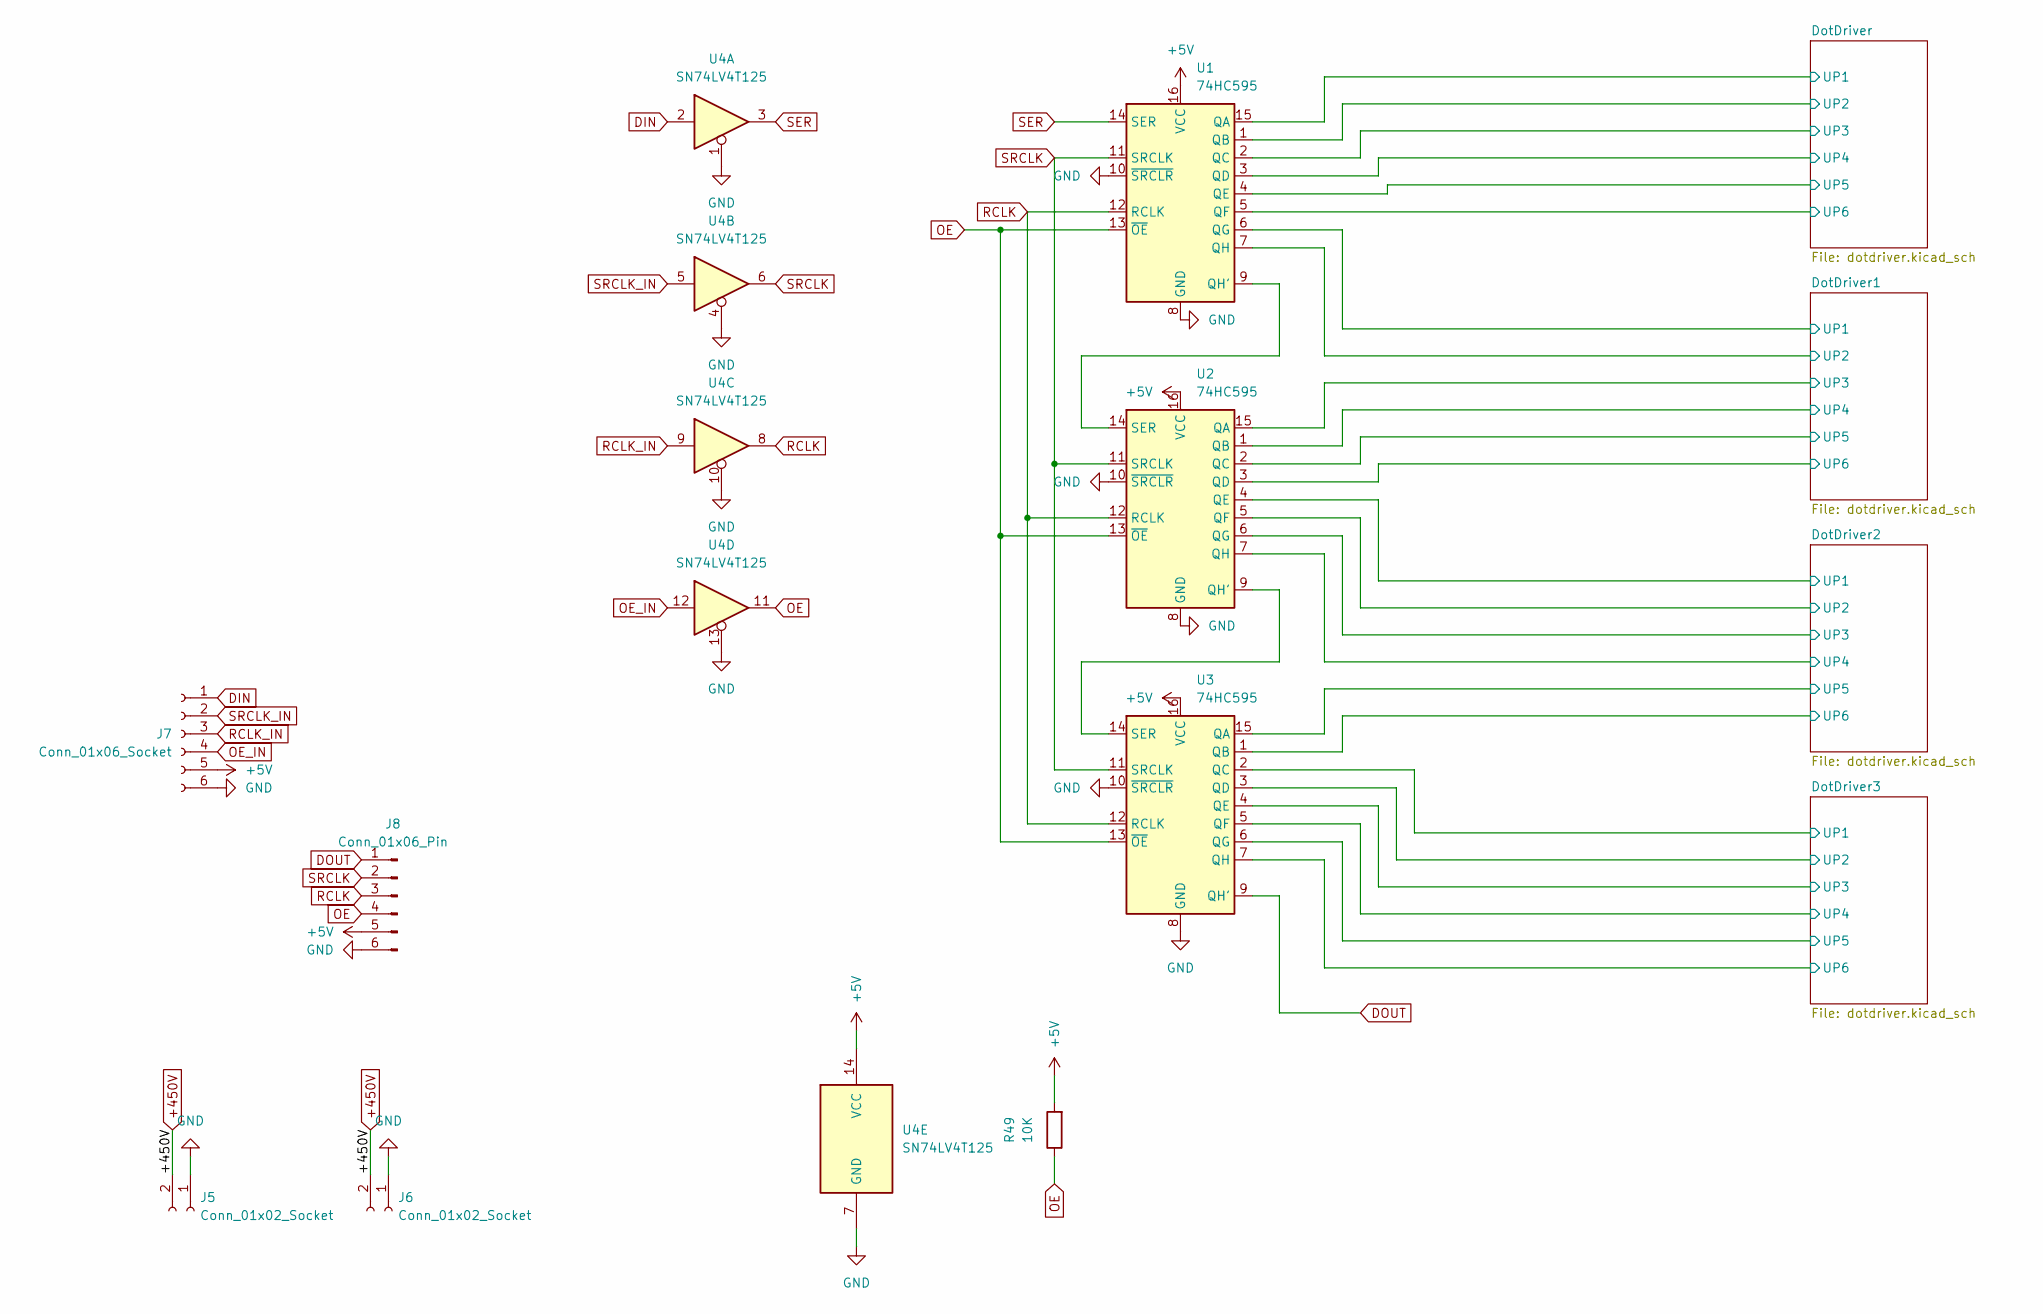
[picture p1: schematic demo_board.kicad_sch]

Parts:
J5, J6: Conn_01x02_Socket; AMASS_XT60-M_1x02_P7.20mm_Vertical
J7: Conn_01x06_Socket; PinSocket_2x03_P2.54mm_Horizontal
J8: Conn_01x06_Pin; PinHeader_2x03_P2.54mm_Horizontal
R49: 10K; R_0603_1608Metric
U1, U2, U3: 74HC595; SOIC-16W_5.3x10.2mm_P1.27mm
U4: SN74LV4T125; TSSOP-14_4.4x5mm_P0.65mm

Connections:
+5V: J7.5, J8.5, R49.2, U1.16 (VCC), U2.16 (VCC), U3.16 (VCC), U4.14 (VCC)
+450V: J5.2, J6.2; also elsewhere on the board
/DotDriver1/UP1: U1.6 (QG); also elsewhere on the board
/DotDriver1/UP2: U1.7 (QH); also elsewhere on the board
/DotDriver1/UP3: U2.15 (QA); also elsewhere on the board
/DotDriver1/UP4: U2.1 (QB); also elsewhere on the board
/DotDriver1/UP5: U2.2 (QC); also elsewhere on the board
/DotDriver1/UP6: U2.3 (QD); also elsewhere on the board
/DotDriver2/UP1: U2.4 (QE); also elsewhere on the board
/DotDriver2/UP2: U2.5 (QF); also elsewhere on the board
/DotDriver2/UP3: U2.6 (QG); also elsewhere on the board
/DotDriver2/UP4: U2.7 (QH); also elsewhere on the board
/DotDriver2/UP5: U3.15 (QA); also elsewhere on the board
/DotDriver2/UP6: U3.1 (QB); also elsewhere on the board
/DotDriver3/UP1: U3.2 (QC); also elsewhere on the board
/DotDriver3/UP2: U3.3 (QD); also elsewhere on the board
/DotDriver3/UP3: U3.4 (QE); also elsewhere on the board
/DotDriver3/UP4: U3.5 (QF); also elsewhere on the board
/DotDriver3/UP5: U3.6 (QG); also elsewhere on the board
/DotDriver3/UP6: U3.7 (QH); also elsewhere on the board
/DotDriver/UP1: U1.15 (QA); also elsewhere on the board
/DotDriver/UP2: U1.1 (QB); also elsewhere on the board
/DotDriver/UP3: U1.2 (QC); also elsewhere on the board
/DotDriver/UP4: U1.3 (QD); also elsewhere on the board
/DotDriver/UP5: U1.4 (QE); also elsewhere on the board
/DotDriver/UP6: U1.5 (QF); also elsewhere on the board
DIN: J7.1, U4.2
DOUT: J8.1, U3.9 (QH')
GND: J5.1, J6.1, J7.6, J8.6, U1.8 (GND), U1.10 (~SRCLR), U2.8 (GND), U2.10 (~SRCLR), U3.8 (GND), U3.10 (~SRCLR), U4.1, U4.4, U4.7 (GND), U4.10, U4.13; also elsewhere on the board
unnamed: U1.9 (QH'), U2.14 (SER)
unnamed: U2.9 (QH'), U3.14 (SER)
OE: J8.4, R49.1, U1.13 (~OE), U2.13 (~OE), U3.13 (~OE), U4.11
OE_IN: J7.4, U4.12
RCLK: J8.3, U1.12 (RCLK), U2.12 (RCLK), U3.12 (RCLK), U4.8
RCLK_IN: J7.3, U4.9
SER: U1.14 (SER), U4.3
SRCLK: J8.2, U1.11 (SRCLK), U2.11 (SRCLK), U3.11 (SRCLK), U4.6
SRCLK_IN: J7.2, U4.5

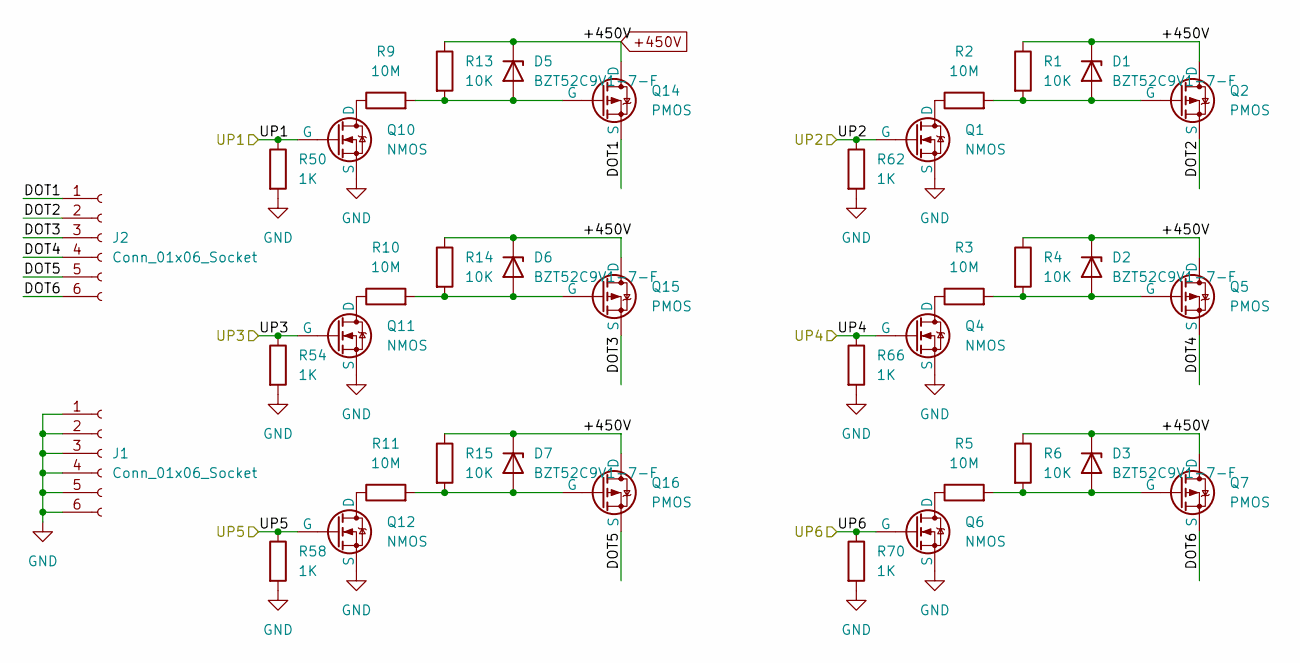
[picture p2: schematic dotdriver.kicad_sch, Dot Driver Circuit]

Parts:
D1, D2, D3, D5, D6, D7: BZT52C9V1-7-F; D_SOD-123
J1, J2: Conn_01x06_Socket; PinSocket_2x03_P2.54mm_Vertical
Q1, Q4, Q6, Q10, Q11, Q12: NMOS; SOT-89-3
Q2, Q5, Q7, Q14, Q15, Q16: PMOS; SOT-89-3
R1, R4, R6, R13, R14, R15: 10K; R_0603_1608Metric
R2, R3, R5, R9, R10, R11: 10M; R_0603_1608Metric
R50, R54, R58, R62, R66, R70: 1K; R_0603_1608Metric

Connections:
+450V: D1.1 (K), D2.1 (K), D3.1 (K), D5.1 (K), D6.1 (K), D7.1 (K), Q2.1 (D), Q5.1 (D), Q7.1 (D), Q14.1 (D), Q15.1 (D), Q16.1 (D), R1.1, R4.1, R6.1, R13.1, R14.1, R15.1; also elsewhere on the board
/DotDriver/DOT1: J2.1, Q14.3 (S)
/DotDriver/DOT2: J2.2, Q2.3 (S)
/DotDriver/DOT3: J2.3, Q15.3 (S)
/DotDriver/DOT4: J2.4, Q5.3 (S)
/DotDriver/DOT5: J2.5, Q16.3 (S)
/DotDriver/DOT6: J2.6, Q7.3 (S)
/DotDriver/UP1: Q10.2 (G), R50.1; also elsewhere on the board
/DotDriver/UP2: Q1.2 (G), R62.1; also elsewhere on the board
/DotDriver/UP3: Q11.2 (G), R54.1; also elsewhere on the board
/DotDriver/UP4: Q4.2 (G), R66.1; also elsewhere on the board
/DotDriver/UP5: Q12.2 (G), R58.1; also elsewhere on the board
/DotDriver/UP6: Q6.2 (G), R70.1; also elsewhere on the board
GND: J1.1, J1.2, J1.3, J1.4, J1.5, J1.6, Q1.3 (S), Q4.3 (S), Q6.3 (S), Q10.3 (S), Q11.3 (S), Q12.3 (S), R50.2, R54.2, R58.2, R62.2, R66.2, R70.2; also elsewhere on the board
unnamed: D1.2 (A), Q2.2 (G), R1.2, R2.2
unnamed: D2.2 (A), Q5.2 (G), R3.2, R4.2
unnamed: D3.2 (A), Q7.2 (G), R5.2, R6.2
unnamed: D5.2 (A), Q14.2 (G), R9.2, R13.2
unnamed: D6.2 (A), Q15.2 (G), R10.2, R14.2
unnamed: D7.2 (A), Q16.2 (G), R11.2, R15.2
unnamed: Q1.1 (D), R2.1
unnamed: Q4.1 (D), R3.1
unnamed: Q6.1 (D), R5.1
unnamed: Q10.1 (D), R9.1
unnamed: Q11.1 (D), R10.1
unnamed: Q12.1 (D), R11.1

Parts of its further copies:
D4, D8, D9, D10, D11, D12, D13, D14, D15, D16, D17, D18, D19, D20, D21, D22, D23, D24: BZT52C9V1-7-F; D_SOD-123
J0, J3, J4, J9, J10, J11: Conn_01x06_Socket; PinSocket_2x03_P2.54mm_Vertical
Q3, Q8, Q9, Q19, Q20, Q21, Q25, Q26, Q27, Q31, Q32, Q33, Q37, Q38, Q39, Q43, Q44, Q45: NMOS; SOT-89-3
Q13, Q17, Q18, Q22, Q23, Q24, Q28, Q29, Q30, Q34, Q35, Q36, Q40, Q41, Q42, Q46, Q47, Q48: PMOS; SOT-89-3
R7, R8, R12, R19, R20, R21, R25, R26, R27, R31, R32, R33, R37, R38, R39, R43, R44, R45: 10M; R_0603_1608Metric
R16, R17, R18, R22, R23, R24, R28, R29, R30, R34, R35, R36, R40, R41, R42, R46, R47, R48: 10K; R_0603_1608Metric
R51, R52, R53, R55, R56, R57, R59, R60, R61, R63, R64, R65, R67, R68, R69, R71, R72, R73: 1K; R_0603_1608Metric

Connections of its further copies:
+450V: D4.1 (K), D8.1 (K), D9.1 (K), D10.1 (K), D11.1 (K), D12.1 (K), D13.1 (K), D14.1 (K), D15.1 (K), D16.1 (K), D17.1 (K), D18.1 (K), D19.1 (K), D20.1 (K), D21.1 (K), D22.1 (K), D23.1 (K), D24.1 (K), Q13.1 (D), Q17.1 (D), Q18.1 (D), Q22.1 (D), Q23.1 (D), Q24.1 (D), Q28.1 (D), Q29.1 (D), Q30.1 (D), Q34.1 (D), Q35.1 (D), Q36.1 (D), Q40.1 (D), Q41.1 (D), Q42.1 (D), Q46.1 (D), Q47.1 (D), Q48.1 (D), R16.1, R17.1, R18.1, R22.1, R23.1, R24.1, R28.1, R29.1, R30.1, R34.1, R35.1, R36.1, R40.1, R41.1, R42.1, R46.1, R47.1, R48.1; also elsewhere on the board
/DotDriver1/DOT1: J0.1, Q13.3 (S)
/DotDriver1/DOT2: J0.2, Q22.3 (S)
/DotDriver1/DOT3: J0.3, Q17.3 (S)
/DotDriver1/DOT4: J0.4, Q23.3 (S)
/DotDriver1/DOT5: J0.5, Q18.3 (S)
/DotDriver1/DOT6: J0.6, Q24.3 (S)
/DotDriver1/UP1: Q3.2 (G), R51.1; also elsewhere on the board
/DotDriver1/UP2: Q19.2 (G), R63.1; also elsewhere on the board
/DotDriver1/UP3: Q8.2 (G), R55.1; also elsewhere on the board
/DotDriver1/UP4: Q20.2 (G), R67.1; also elsewhere on the board
/DotDriver1/UP5: Q9.2 (G), R59.1; also elsewhere on the board
/DotDriver1/UP6: Q21.2 (G), R71.1; also elsewhere on the board
/DotDriver2/DOT1: J3.1, Q28.3 (S)
/DotDriver2/DOT2: J3.2, Q34.3 (S)
/DotDriver2/DOT3: J3.3, Q29.3 (S)
/DotDriver2/DOT4: J3.4, Q35.3 (S)
/DotDriver2/DOT5: J3.5, Q30.3 (S)
/DotDriver2/DOT6: J3.6, Q36.3 (S)
/DotDriver2/UP1: Q25.2 (G), R52.1; also elsewhere on the board
/DotDriver2/UP2: Q31.2 (G), R64.1; also elsewhere on the board
/DotDriver2/UP3: Q26.2 (G), R56.1; also elsewhere on the board
/DotDriver2/UP4: Q32.2 (G), R68.1; also elsewhere on the board
/DotDriver2/UP5: Q27.2 (G), R60.1; also elsewhere on the board
/DotDriver2/UP6: Q33.2 (G), R72.1; also elsewhere on the board
/DotDriver3/DOT1: J4.1, Q40.3 (S)
/DotDriver3/DOT2: J4.2, Q46.3 (S)
/DotDriver3/DOT3: J4.3, Q41.3 (S)
/DotDriver3/DOT4: J4.4, Q47.3 (S)
/DotDriver3/DOT5: J4.5, Q42.3 (S)
/DotDriver3/DOT6: J4.6, Q48.3 (S)
/DotDriver3/UP1: Q37.2 (G), R53.1; also elsewhere on the board
/DotDriver3/UP2: Q43.2 (G), R65.1; also elsewhere on the board
/DotDriver3/UP3: Q38.2 (G), R57.1; also elsewhere on the board
/DotDriver3/UP4: Q44.2 (G), R69.1; also elsewhere on the board
/DotDriver3/UP5: Q39.2 (G), R61.1; also elsewhere on the board
/DotDriver3/UP6: Q45.2 (G), R73.1; also elsewhere on the board
GND: J9.1, J9.2, J9.3, J9.4, J9.5, J9.6, J10.1, J10.2, J10.3, J10.4, J10.5, J10.6, J11.1, J11.2, J11.3, J11.4, J11.5, J11.6, Q3.3 (S), Q8.3 (S), Q9.3 (S), Q19.3 (S), Q20.3 (S), Q21.3 (S), Q25.3 (S), Q26.3 (S), Q27.3 (S), Q31.3 (S), Q32.3 (S), Q33.3 (S), Q37.3 (S), Q38.3 (S), Q39.3 (S), Q43.3 (S), Q44.3 (S), Q45.3 (S), R51.2, R52.2, R53.2, R55.2, R56.2, R57.2, R59.2, R60.2, R61.2, R63.2, R64.2, R65.2, R67.2, R68.2, R69.2, R71.2, R72.2, R73.2; also elsewhere on the board
unnamed: D4.2 (A), Q13.2 (G), R7.2, R16.2
unnamed: D8.2 (A), Q17.2 (G), R8.2, R17.2
unnamed: D9.2 (A), Q18.2 (G), R12.2, R18.2
unnamed: D10.2 (A), Q22.2 (G), R19.2, R22.2
unnamed: D11.2 (A), Q23.2 (G), R20.2, R23.2
unnamed: D12.2 (A), Q24.2 (G), R21.2, R24.2
unnamed: D13.2 (A), Q28.2 (G), R25.2, R28.2
unnamed: D14.2 (A), Q29.2 (G), R26.2, R29.2
unnamed: D15.2 (A), Q30.2 (G), R27.2, R30.2
unnamed: D16.2 (A), Q34.2 (G), R31.2, R34.2
unnamed: D17.2 (A), Q35.2 (G), R32.2, R35.2
unnamed: D18.2 (A), Q36.2 (G), R33.2, R36.2
unnamed: D19.2 (A), Q40.2 (G), R37.2, R40.2
unnamed: D20.2 (A), Q41.2 (G), R38.2, R41.2
unnamed: D21.2 (A), Q42.2 (G), R39.2, R42.2
unnamed: D22.2 (A), Q46.2 (G), R43.2, R46.2
unnamed: D23.2 (A), Q47.2 (G), R44.2, R47.2
unnamed: D24.2 (A), Q48.2 (G), R45.2, R48.2
unnamed: Q3.1 (D), R7.1
unnamed: Q8.1 (D), R8.1
unnamed: Q9.1 (D), R12.1
unnamed: Q19.1 (D), R19.1
unnamed: Q20.1 (D), R20.1
unnamed: Q21.1 (D), R21.1
unnamed: Q25.1 (D), R25.1
unnamed: Q26.1 (D), R26.1
unnamed: Q27.1 (D), R27.1
unnamed: Q31.1 (D), R31.1
unnamed: Q32.1 (D), R32.1
unnamed: Q33.1 (D), R33.1
unnamed: Q37.1 (D), R37.1
unnamed: Q38.1 (D), R38.1
unnamed: Q39.1 (D), R39.1
unnamed: Q43.1 (D), R43.1
unnamed: Q44.1 (D), R44.1
unnamed: Q45.1 (D), R45.1

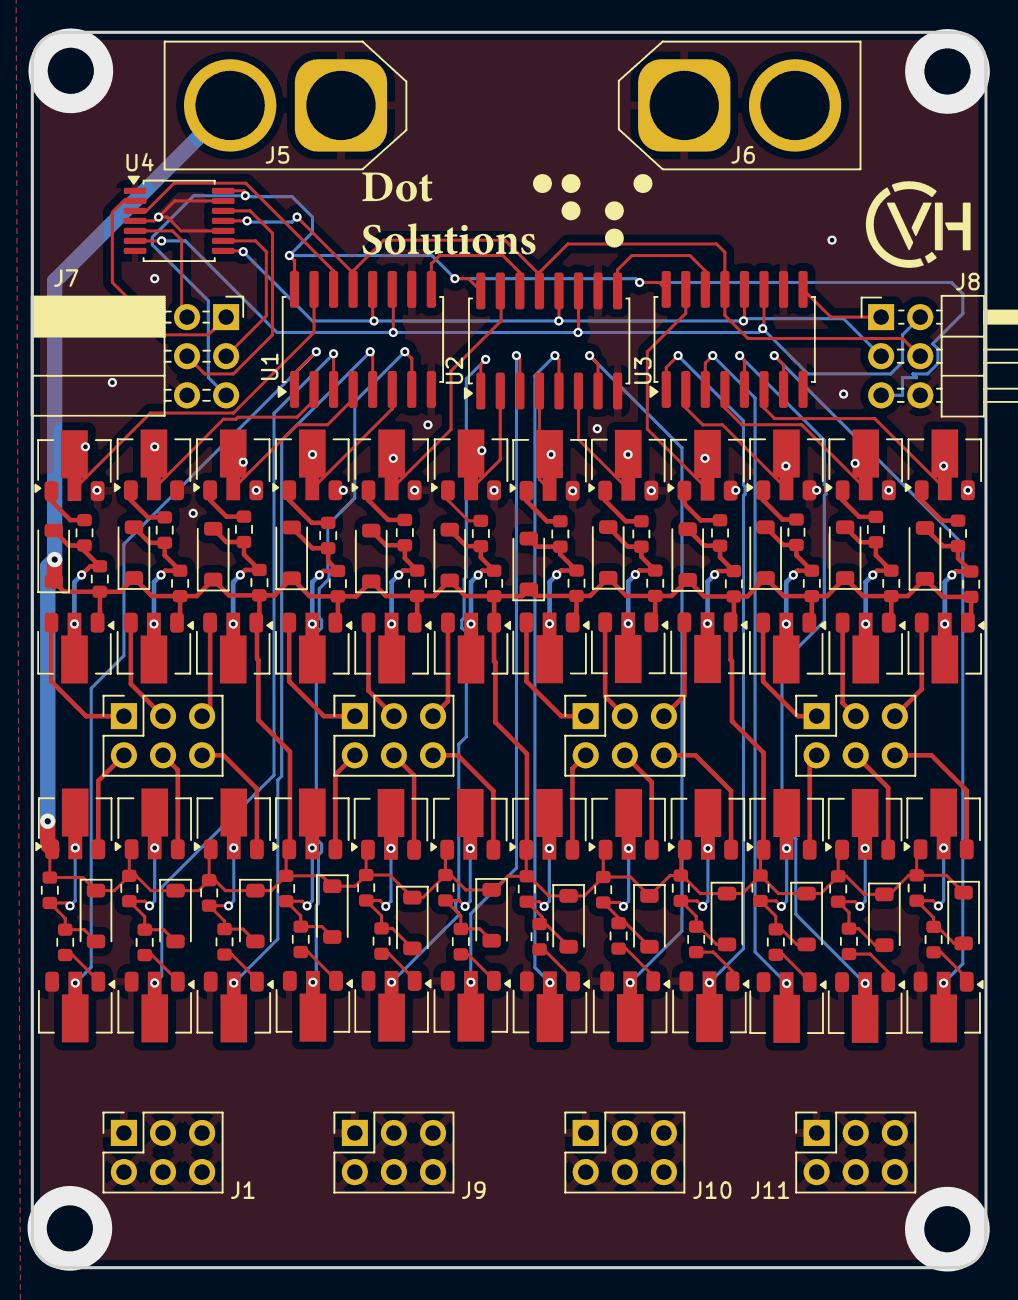
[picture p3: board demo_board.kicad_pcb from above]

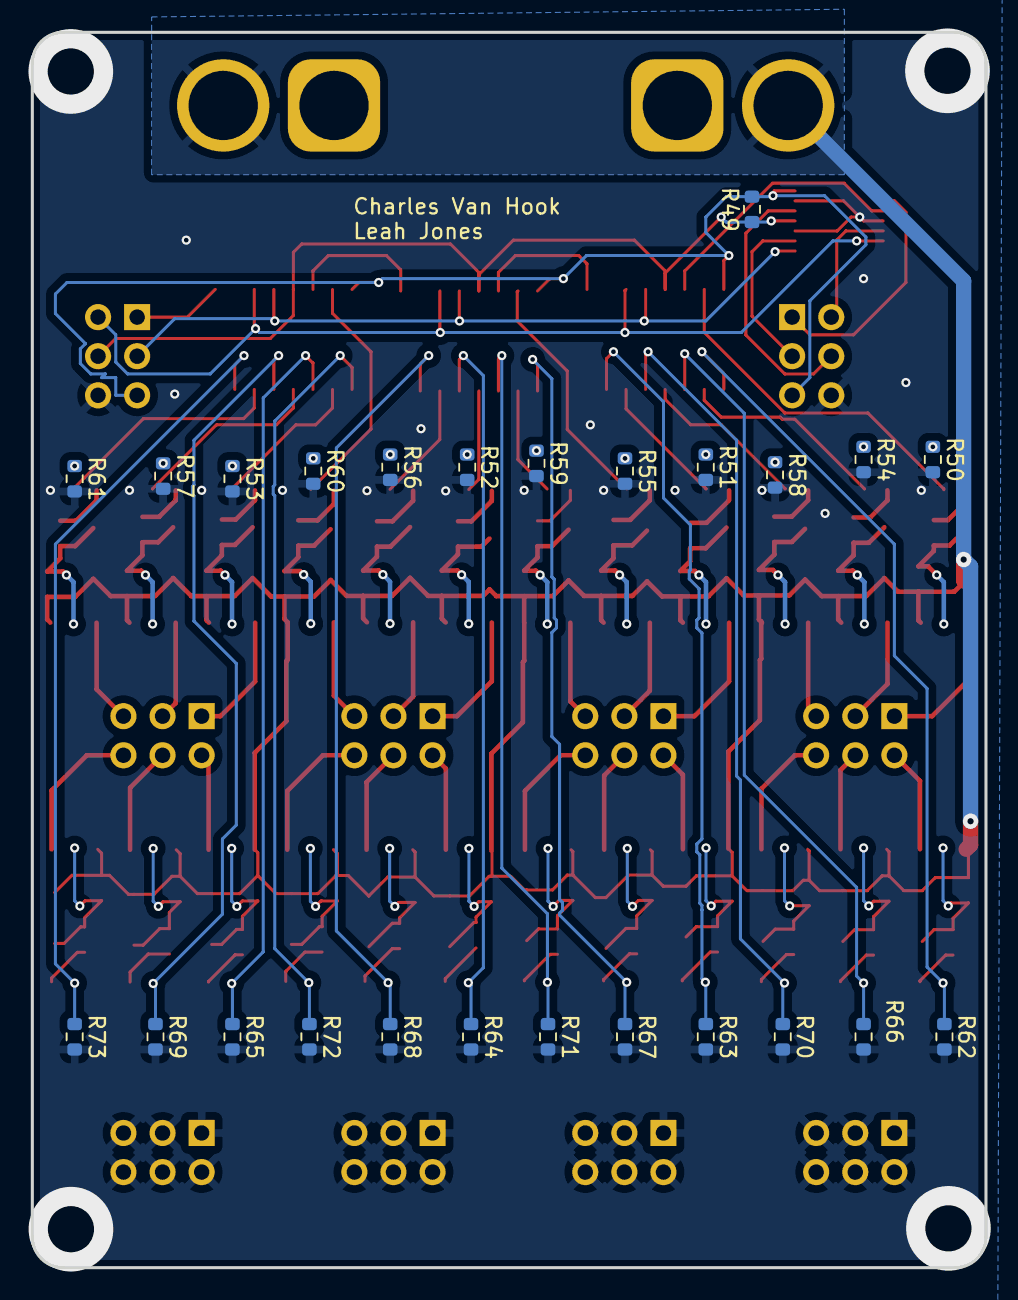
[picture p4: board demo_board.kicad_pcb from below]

Board: 2 copper layers, 62.0 x 80.2 mm, 161 parts (25 on the bottom side), 110 nets.

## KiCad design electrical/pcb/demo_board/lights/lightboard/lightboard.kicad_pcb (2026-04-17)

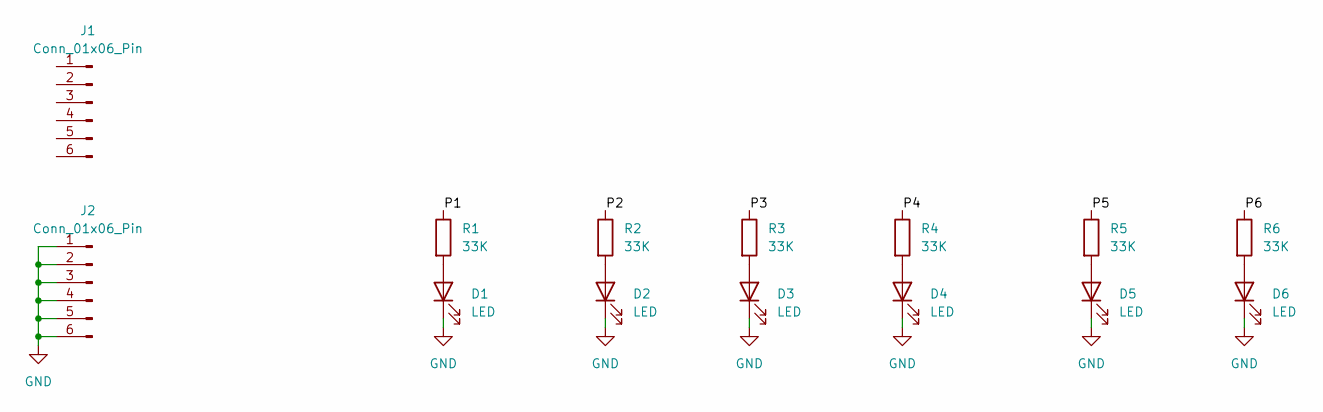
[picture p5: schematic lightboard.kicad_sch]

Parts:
D1, D2, D3, D4, D5, D6: LED; LED_0805_2012Metric
J1, J2: Conn_01x06_Pin
R1, R2, R3, R4, R5, R6: 33K; R_1210_3225Metric

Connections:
/P1: J1.6, R1.1
/P2: J1.1, R2.1
/P3: J1.3, R3.1
/P4: J1.4, R4.1
/P5: J1.2, R5.1
/P6: J1.5, R6.1
GND: D1.1 (K), D2.1 (K), D3.1 (K), D4.1 (K), D5.1 (K), D6.1 (K), J2.1, J2.2, J2.3, J2.4, J2.5, J2.6
unnamed: D1.2 (A), R1.2
unnamed: D2.2 (A), R2.2
unnamed: D3.2 (A), R3.2
unnamed: D4.2 (A), R4.2
unnamed: D5.2 (A), R5.2
unnamed: D6.2 (A), R6.2

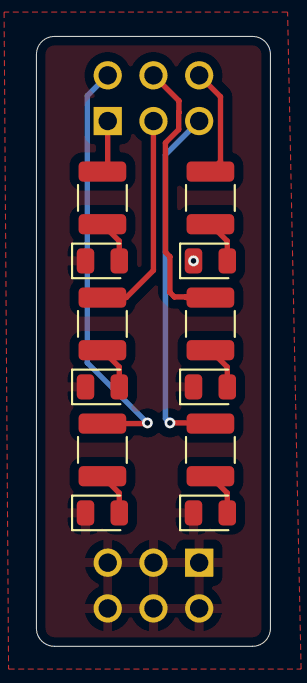
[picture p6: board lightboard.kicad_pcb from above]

Board: 2 copper layers, 13.0 x 33.9 mm, 14 parts (0 on the bottom side), 13 nets.

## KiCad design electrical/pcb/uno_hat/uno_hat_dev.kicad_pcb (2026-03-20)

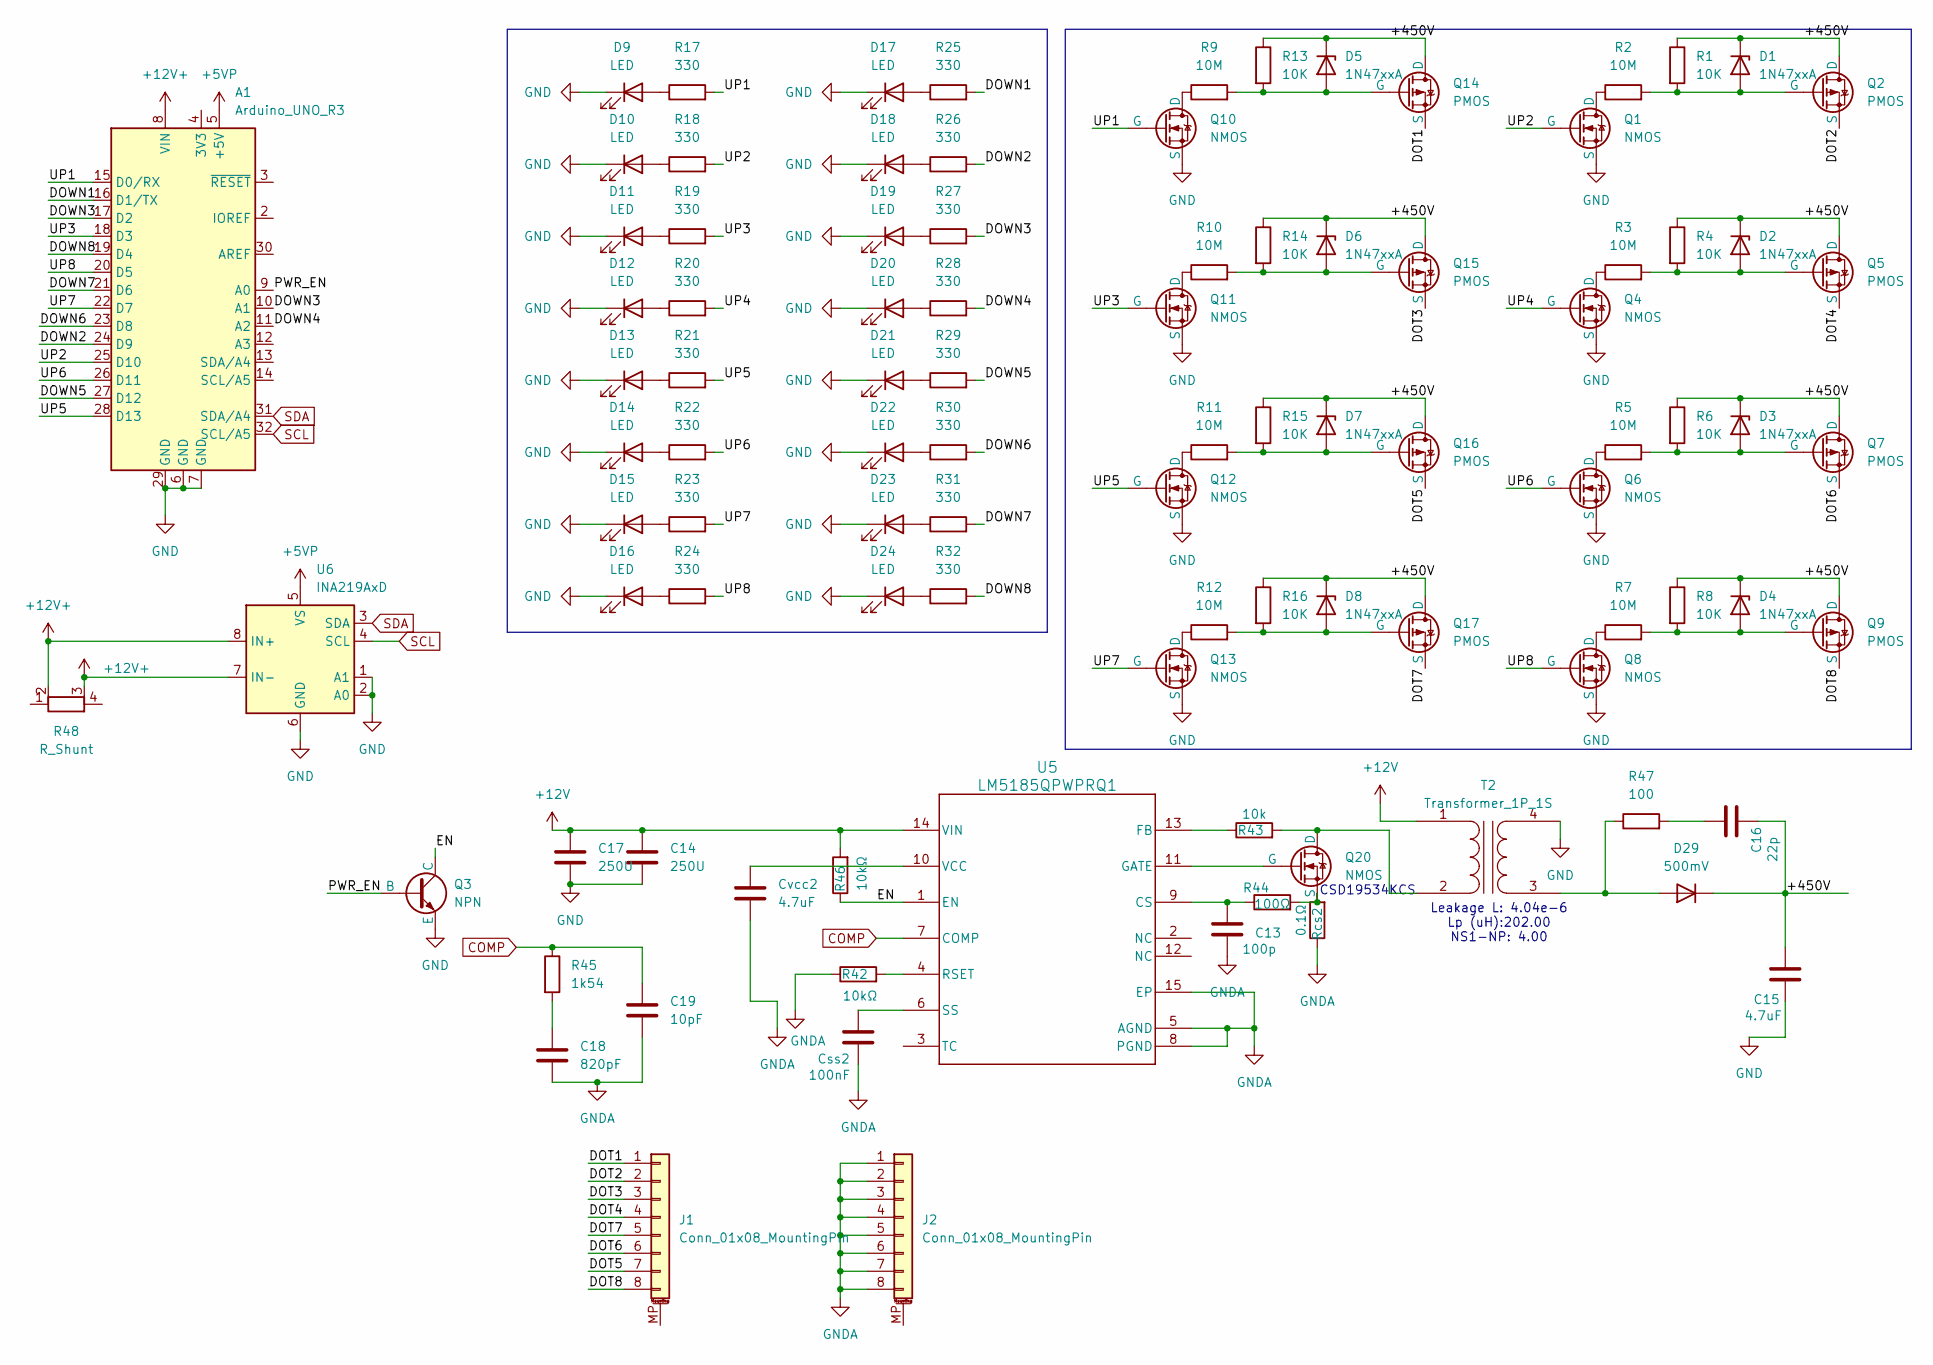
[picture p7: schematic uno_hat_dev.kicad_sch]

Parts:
A1: Arduino_UNO_R3
C13: 100p; R_0805_2012Metric
C14, C17: 250U; CP_Radial_Tantal_D8.0mm_P2.50mm
C15: 4.7uF; R_0805_2012Metric
C16: 22p; R_0805_2012Metric
C18: 820pF; R_0805_2012Metric
C19: 10pF; R_0805_2012Metric
Css2: 100nF; R_0805_2012Metric
Cvcc2: 4.7uF; R_0805_2012Metric
D1, D2, D3, D4, D5, D6, D7, D8: 1N47xxA; D_DO-41_SOD81_P10.16mm_Horizontal
D9, D10, D11, D12, D13, D14, D15, D16, D17, D18, D19, D20, D21, D22, D23, D24: LED; LED_0805_2012Metric
D29: 500mV; D_A-405_P12.70mm_Horizontal
J1, J2: Conn_01x08_MountingPin; Amphenol_F32Q-1A7x1-11008_1x08-1MP_P0.5mm_Horizontal
Q1, Q4, Q6, Q8, Q10, Q11, Q12, Q13: NMOS; TO-92_Inline
Q2, Q5, Q7, Q9, Q14, Q15, Q16, Q17: PMOS; TO-92_Inline
Q3: NPN; TO-92_Inline
Q20: NMOS; TO-220-3_Vertical
R1, R4, R6, R8, R13, R14, R15, R16: 10K; R_Axial_DIN0207_L6.3mm_D2.5mm_P7.62mm_Horizontal
R2, R3, R5, R7, R9, R10, R11, R12: 10M; R_Axial_DIN0207_L6.3mm_D2.5mm_P7.62mm_Horizontal
R17, R18, R19, R20, R21, R22, R23, R24, R25, R26, R27, R28, R29, R30, R31, R32: 330; R_0805_2012Metric
R42, R46: 10kΩ; R_0805_2012Metric
R43: 10k; R_0805_2012Metric
R44: 100Ω; R_0805_2012Metric
R45: 1k54; R_0805_2012Metric
R47: 100; R_0805_2012Metric
R48: R_Shunt; R_Shunt_Ohmite_LVK24
Rcs2: 0.1Ω; R_0805_2012Metric
T2: Transformer_1P_1S; PinSocket_1x04_P2.54mm_Vertical
U5: LM5185QPWPRQ1; Texas_HTSSOP-14-1EP_4.4x5mm_P0.65mm_EP3.4x5mm_Mask3.155x3.2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
U6: INA219AxD; SOIC-8_3.9x4.9mm_P1.27mm

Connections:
+5VP: A1.5 (+5V), U6.5 (VS)
+12V: C14.1, C17.1, R46.2, T2.1 (AA), U5.14 (VIN)
+12V+: A1.8 (VIN), R48.2, R48.3, U6.7 (IN-), U6.8 (IN+)
/+450V: C15.1, C16.2, D1.1 (K), D2.1 (K), D3.1 (K), D4.1 (K), D5.1 (K), D6.1 (K), D7.1 (K), D8.1 (K), D29.1 (K), Q2.1 (D), Q5.1 (D), Q7.1 (D), Q9.1 (D), Q14.1 (D), Q15.1 (D), Q16.1 (D), Q17.1 (D), R1.1, R4.1, R6.1, R8.1, R13.1, R14.1, R15.1, R16.1
/DOT1: J1.1, Q14.3 (S)
/DOT2: J1.2, Q2.3 (S)
/DOT3: J1.3, Q15.3 (S)
/DOT4: J1.4, Q5.3 (S)
/DOT5: J1.7, Q16.3 (S)
/DOT6: J1.6, Q7.3 (S)
/DOT7: J1.5, Q17.3 (S)
/DOT8: J1.8, Q9.3 (S)
/DOWN1: A1.16 (D1/TX), R25.2
/DOWN2: A1.24 (D9), R26.2
/DOWN3: A1.10 (A1), A1.17 (D2), R27.2
/DOWN4: A1.11 (A2), R28.2
/DOWN5: A1.27 (D12), R29.2
/DOWN6: A1.23 (D8), R30.2
/DOWN7: A1.21 (D6), R31.2
/DOWN8: A1.19 (D4), R32.2
/EN: Q3.1 (C), R46.1, U5.1 (EN)
/PWR_EN: A1.9 (A0), Q3.2 (B)
/UP1: A1.15 (D0/RX), Q10.2 (G), R17.2
/UP2: A1.25 (D10), Q1.2 (G), R18.2
/UP3: A1.18 (D3), Q11.2 (G), R19.2
/UP4: Q4.2 (G), R20.2
/UP5: A1.28 (D13), Q12.2 (G), R21.2
/UP6: A1.26 (D11), Q6.2 (G), R22.2
/UP7: A1.22 (D7), Q13.2 (G), R23.2
/UP8: A1.20 (D5), Q8.2 (G), R24.2
COMP: C19.1, R45.1, U5.7 (COMP)
GND: A1.6 (GND), A1.7 (GND), A1.29 (GND), C14.2, C15.2, C17.2, D9.1 (K), D10.1 (K), D11.1 (K), D12.1 (K), D13.1 (K), D14.1 (K), D15.1 (K), D16.1 (K), D17.1 (K), D18.1 (K), D19.1 (K), D20.1 (K), D21.1 (K), D22.1 (K), D23.1 (K), D24.1 (K), Q1.3 (S), Q3.3 (E), Q4.3 (S), Q6.3 (S), Q8.3 (S), Q10.3 (S), Q11.3 (S), Q12.3 (S), Q13.3 (S), T2.4 (SB), U6.1 (A1), U6.2 (A0), U6.6 (GND)
GNDA: C13.2, C18.2, C19.2, Css2.2, Cvcc2.2, J2.1, J2.2, J2.3, J2.4, J2.5, J2.6, J2.7, J2.8, R42.1, Rcs2.1, U5.5 (AGND), U5.8 (PGND), U5.15 (EP)
unnamed: C16.1, R47.2
unnamed: C18.1, R45.2
unnamed: D1.2 (A), Q2.2 (G), R1.2, R2.2
unnamed: D2.2 (A), Q5.2 (G), R3.2, R4.2
unnamed: D3.2 (A), Q7.2 (G), R5.2, R6.2
unnamed: D4.2 (A), Q9.2 (G), R7.2, R8.2
unnamed: D5.2 (A), Q14.2 (G), R9.2, R13.2
unnamed: D6.2 (A), Q15.2 (G), R10.2, R14.2
unnamed: D7.2 (A), Q16.2 (G), R11.2, R15.2
unnamed: D8.2 (A), Q17.2 (G), R12.2, R16.2
unnamed: D9.2 (A), R17.1
unnamed: D10.2 (A), R18.1
unnamed: D11.2 (A), R19.1
unnamed: D12.2 (A), R20.1
unnamed: D13.2 (A), R21.1
unnamed: D14.2 (A), R22.1
unnamed: D15.2 (A), R23.1
unnamed: D16.2 (A), R24.1
unnamed: D17.2 (A), R25.1
unnamed: D18.2 (A), R26.1
unnamed: D19.2 (A), R27.1
unnamed: D20.2 (A), R28.1
unnamed: D21.2 (A), R29.1
unnamed: D22.2 (A), R30.1
unnamed: D23.2 (A), R31.1
unnamed: D24.2 (A), R32.1
unnamed: D29.2 (A), R47.1, T2.3 (SA)
unnamed: Q1.1 (D), R2.1
unnamed: Q4.1 (D), R3.1
unnamed: Q6.1 (D), R5.1
unnamed: Q8.1 (D), R7.1
unnamed: Q10.1 (D), R9.1
unnamed: Q11.1 (D), R10.1
unnamed: Q12.1 (D), R11.1
unnamed: Q13.1 (D), R12.1
unnamed: Q20.1 (D), R43.2, T2.2 (AB)
unnamed: Q20.2 (G), U5.11 (GATE)
unnamed: Q20.3 (S), R44.2, Rcs2.2
unnamed: C13.1, R44.1, U5.9 (CS)
unnamed: R43.1, U5.13 (FB)
unnamed: R42.2, U5.4 (RSET)
unnamed: Css2.1, U5.6 (SS)
unnamed: Cvcc2.1, U5.10 (VCC)
SCL: A1.32 (SCL/A5), U6.4 (SCL)
SDA: A1.31 (SDA/A4), U6.3 (SDA)

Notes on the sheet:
Leakage L: 4.04e-6 Lp (uH):202.00 NS1-NP: 4.00
CSD19534KCS

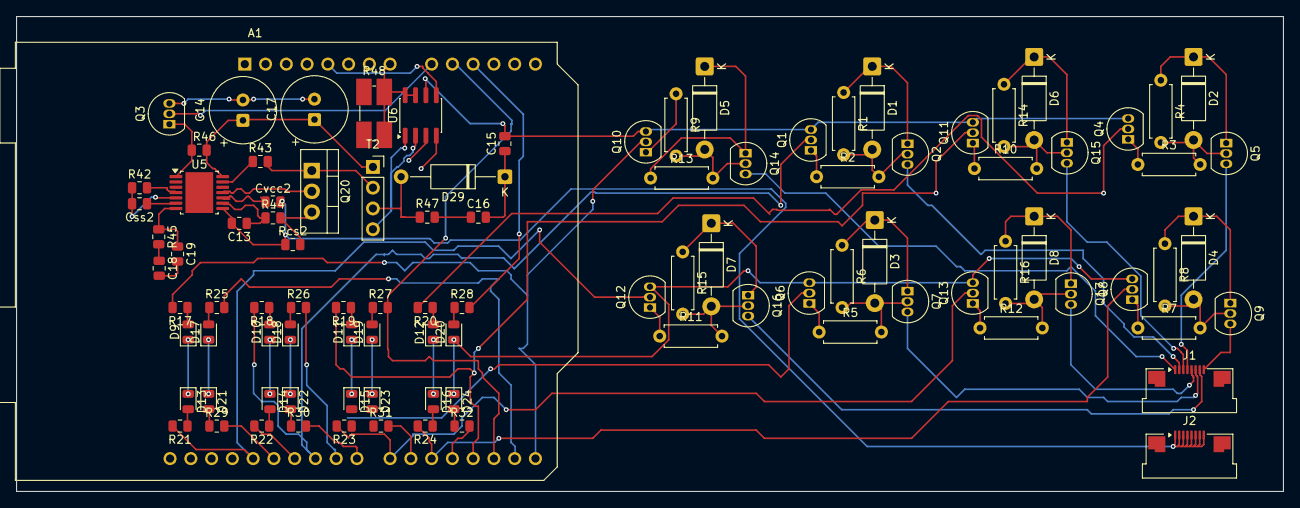
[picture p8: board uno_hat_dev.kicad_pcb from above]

Board: 2 copper layers, 155.0 x 58.1 mm, 98 parts (0 on the bottom side), 78 nets.

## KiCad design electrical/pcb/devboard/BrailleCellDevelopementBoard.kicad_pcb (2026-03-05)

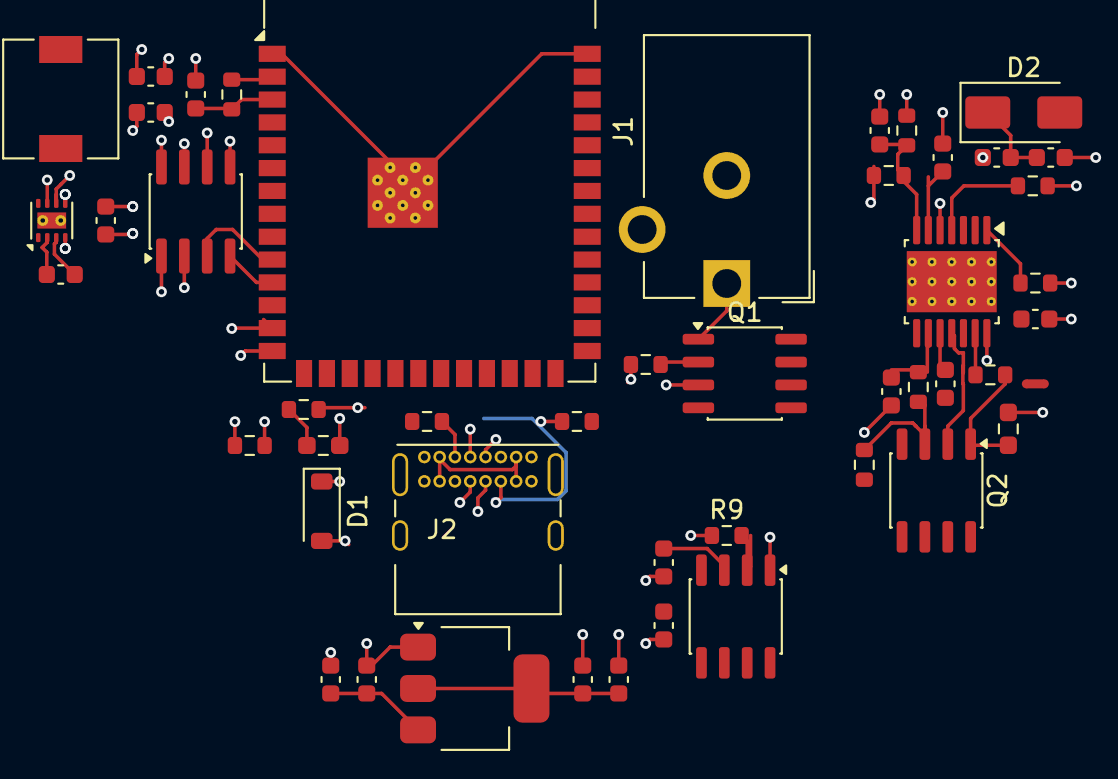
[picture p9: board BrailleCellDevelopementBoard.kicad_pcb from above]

Board: 4 copper layers, 48 parts (0 on the bottom side), 33 nets.

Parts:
C1: 4uF; C_0603_1608Metric
C2: 1.2uF; C_0603_1608Metric
C3: 47pF; C_0603_1608Metric
C7: CIN; C_0603_1608Metric
C10, C11, C12, C13, C14: C; C_0603_1608Metric
C15, C17: 10uF; C_0603_1608Metric
C16, C18, C20: 0.1uF; C_0603_1608Metric
C19: 22uF; C_0603_1608Metric
Chf1: 120pF; C_0603_1608Metric
Css1: 100nF; C_0603_1608Metric
Cvcc1: 1uF; C_0603_1608Metric
D1: D_Zener; D_SOD-123
D2: 500mV; D_SMA
J1: Barrel_Jack; BarrelJack_CUI_PJ-102AH_Horizontal
J2: USB_C_Receptacle_USB2.0_14P; USB_C_Receptacle_GCT_USB4085
L2: 2.2uH; L_6.3x6.3_H3
NT1: NetTie_2; NetTie-2_SMD_Pad0.5mm
Q1, Q2: NMOS; SO-8_3.9x4.9mm_P1.27mm
Q3: PMOS; SO-8_3.9x4.9mm_P1.27mm
R1, R8: R; R_0603_1608Metric
R2: 100Ω; R_0603_1608Metric
R3: 360kΩ; R_0603_1608Metric
R4: 10kΩ; R_0603_1608Metric
R5, R6: RCOMP; R_0603_1608Metric
R9: 100K; R_0603_1608Metric
R10, R11: 5.1k; R_0603_1608Metric
R12: 10k; R_0603_1608Metric
R13: R_Shunt; R_0603_1608Metric
Rcs1: 0.1Ω; R_0603_1608Metric
Rtop1: 200kΩ; R_0603_1608Metric
T1: Transformer_1P_1S; R_0603_1608Metric_Pad0.98x0.95mm_HandSolder
TH1: Thermistor_NTC; R_0603_1608Metric_Pad0.98x0.95mm_HandSolder
U2: ESP32-S3-WROOM-1
U3: AMS1117-3.3; SOT-223-3_TabPin2
U4: TPS62162DSG; WSON-8-1EP_2x2mm_P0.5mm_EP0.9x1.6mm_ThermalVias
U5: INA219AxD; SOIC-8_3.9x4.9mm_P1.27mm
U6: LM5185QPWPRQ1; Texas_HTSSOP-14-1EP_4.4x5mm_P0.65mm_EP3.4x5mm_Mask3.155x3.2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

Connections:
+3.3V: C13.1, C14.1, U3.2 (VO)
+5V: C11.1, C12.1, C16.1, C17.1, C18.2, Q3.1 (D), U3.3 (VI), U4.3 (EN)
+24V: C3.2, C7.1, Chf1.2, Css1.2, D1.1 (K), NT1.2, Q1.3 (S), R4.1, R5.2, R6.2, R9.1, R13.1, R13.2, Rtop1.1, T1.1 (AA), U5.7 (IN-), U5.8 (IN+), U6.5 (AGND), U6.14 (VIN), U6.15 (EP)
/MCU/3V3: R8.1, U2.2 (3V3)
/MCU/USB_DM: J2.A7 (D-), J2.B7 (D-), U2.13 (USB_D-)
/MCU/USB_DP: J2.A6 (D+), J2.B6 (D+), U2.14 (USB_D+)
/PowerSystem/+3V3: R12.1, U5.5 (VS)
/PowerSystem/+450V: C1.1, C2.1, D2.1 (K)
/PowerSystem/TEMP_VAL: R12.2, TH1.2
CHIP_PU: C10.1, R8.2, U2.3 (EN)
COMP: Chf1.1, R5.1, R6.1, U6.7 (COMP)
GND: C1.2, C2.2, C10.2, C11.2, C12.2, C13.2, C14.2, C15.2, C16.2, C17.2, C19.1, C19.2, C20.1, C20.2, D1.2 (A), J1.2, J2.A1 (GND), J2.A12 (GND), J2.B1 (GND), J2.B12 (GND), L2.2, R1.2, R10.2, R11.2, TH1.1, U3.1 (GND), U4.4 (AGND), U4.5 (FB), U4.6 (VOS), U5.1 (A1), U5.2 (A0), U5.6 (GND)
GNDPWR: C7.2, Cvcc1.2, NT1.1, Rcs1.1, U6.8 (PGND)
unnamed: J2.A5 (CC1), R11.1
unnamed: J2.B5 (CC2), R10.1
unnamed: J1.1, Q1.1 (D)
unnamed: Q1.2 (G), R1.1
unnamed: Q2.1 (D), R3.2, T1.2 (AB)
unnamed: Q2.2 (G), U6.11 (GATE)
unnamed: Q2.3 (S), R2.2, Rcs1.2
unnamed: Q3.2 (G), R9.2
unnamed: C15.1, J2.A4 (VBUS), J2.A9 (VBUS), J2.B4 (VBUS), J2.B9 (VBUS), Q3.3 (S)
unnamed: U2.1 (GND), U2.40 (GND), U2.41 (GND)
unnamed: L2.1, U4.7 (SW)
unnamed: C18.1, U4.2 (VIN)
unnamed: C3.1, R2.1, U6.9 (CS)
unnamed: Rtop1.2, U6.1 (EN)
unnamed: R3.1, U6.13 (FB)
unnamed: R4.2, U6.4 (RSET)
unnamed: Css1.1, U6.6 (SS)
unnamed: Cvcc1.1, U6.10 (VCC)
SCL: U2.11 (IO18), U5.4 (SCL)
SDA: U2.10 (IO17), U5.3 (SDA)

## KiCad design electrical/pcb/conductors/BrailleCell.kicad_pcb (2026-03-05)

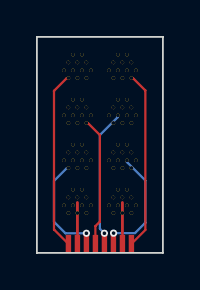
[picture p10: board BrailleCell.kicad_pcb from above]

Board: 2 copper layers, 7.0 x 12.0 mm, 9 parts (0 on the bottom side), 8 nets.

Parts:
CONDUCTOR: Conn_01x08_Socket; FPC Connecotr
J2, J3, J4, J5, J6, J7, J8, J9: Conn_01x01_Pin; Pump Pin

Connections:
unnamed: CONDUCTOR.1, J2.1
unnamed: CONDUCTOR.2, J3.1
unnamed: CONDUCTOR.3, J4.1
unnamed: CONDUCTOR.4, J5.1
unnamed: CONDUCTOR.5, J6.1
unnamed: CONDUCTOR.6, J7.1
unnamed: CONDUCTOR.7, J8.1
unnamed: CONDUCTOR.8, J9.1

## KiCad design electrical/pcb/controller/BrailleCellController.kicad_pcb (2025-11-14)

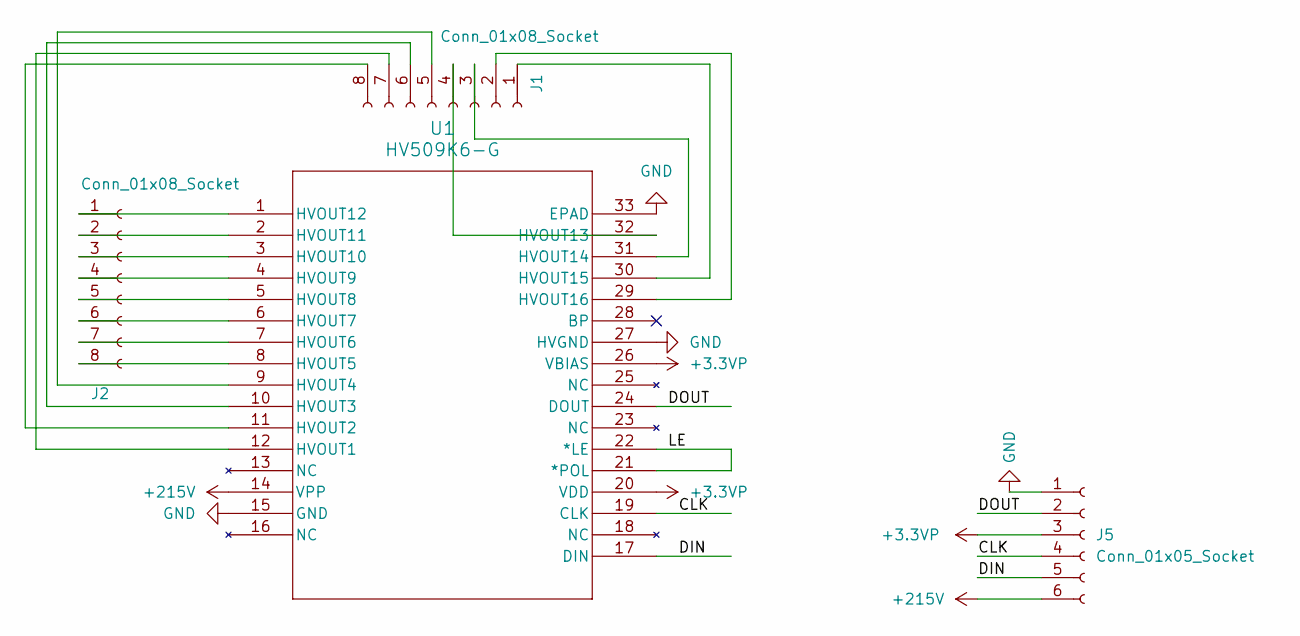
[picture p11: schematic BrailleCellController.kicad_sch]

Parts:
J1, J2: Conn_01x08_Socket; FPC Connecotr
J5: Conn_01x05_Socket; PinHeader_1x06_P1.00mm_Vertical
U1: HV509K6-G; QFN32_5X5MC_MCH

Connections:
+3.3VP: J5.3, U1.20 (VDD), U1.26 (VBIAS)
+215V: J5.6, U1.14 (VPP)
/CLK: J5.4, U1.19 (CLK)
/DIN: J5.5, U1.17 (DIN)
/DOUT: J5.2, U1.24 (DOUT)
/LE: U1.21 (*POL), U1.22 (*LE)
GND: J5.1, U1.15 (GND), U1.27 (HVGND), U1.33 (EPAD)
unnamed: J1.1, U1.30 (HVOUT15)
unnamed: J1.2, U1.29 (HVOUT16)
unnamed: J1.3, U1.31 (HVOUT14)
unnamed: J1.4, U1.32 (HVOUT13)
unnamed: J1.5, U1.9 (HVOUT4)
unnamed: J1.6, U1.10 (HVOUT3)
unnamed: J1.7, U1.12 (HVOUT1)
unnamed: J1.8, U1.11 (HVOUT2)
unnamed: J2.1, U1.1 (HVOUT12)
unnamed: J2.2, U1.2 (HVOUT11)
unnamed: J2.3, U1.3 (HVOUT10)
unnamed: J2.4, U1.4 (HVOUT9)
unnamed: J2.5, U1.5 (HVOUT8)
unnamed: J2.6, U1.6 (HVOUT7)
unnamed: J2.7, U1.7 (HVOUT6)
unnamed: J2.8, U1.8 (HVOUT5)

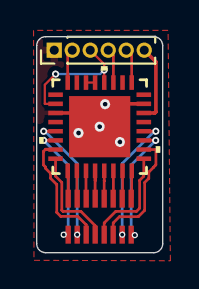
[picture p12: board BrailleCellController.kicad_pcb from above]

Board: 2 copper layers, 7.0 x 12.0 mm, 4 parts (0 on the bottom side), 23 nets.

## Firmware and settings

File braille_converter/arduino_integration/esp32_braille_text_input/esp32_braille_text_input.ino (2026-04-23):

/*
 * ESP32 — Braille Text Input (Serial + Wi-Fi TCP)
 *
 * Commands (newline-terminated, accepted on both Serial and TCP):
 *   TEXT:<string>        — convert text → braille, display char by char
 *   DELAY:<ms>           — set display time per character (default 1000 ms)
 *   DOTS:<1,2,...>       — raise specific dots 1–8
 *   DOTS:NONE            — clear all LEDs
 *   TEST                 — sweep all 8 LEDs one by one
 *   PING                 — reply PONG
 *   HELP                 — list all commands
 *
 * Wi-Fi: connects to WIFI_SSID at boot, then starts a TCP server on TCP_PORT.
 * The serial monitor prints "WIFI:Connected IP=<addr>" once online.
 * Enter that IP in the Flask web interface (WiFi TCP mode, port 3333).
 *
 * 8-dot Braille layout:
 *   Dot 1 • • Dot 4
 *   Dot 2 • • Dot 5
 *   Dot 3 • • Dot 6
 *   Dot 7 • • Dot 8   (dot 7 = capital indicator, dot 8 = number indicator)
 *
 * Wiring (DOT_PINS — adjust for your board):
 *   DOT_PINS[0] → dot 1 → LED + resistor → GND
 *   ...
 *   DOT_PINS[7] → dot 8 → LED + resistor → GND
 * Avoid GPIO 6-11 (SPI flash) and 34-39 (input-only) on ESP32-WROOM.
 */

#include <Arduino.h>
#include <WiFi.h>

// ── Wi-Fi credentials — update before flashing ──────────────────────────────
const char* WIFI_SSID = "BU Guest (unencrypted)";
const char* WIFI_PASS = "";

// ── Network config ───────────────────────────────────────────────────────────
static const uint16_t TCP_PORT                = 3333;
static const uint32_t WIFI_CONNECT_TIMEOUT_MS = 15000;
static const uint32_t WIFI_RETRY_LOG_MS       = 2000;

// ── Pin configuration ────────────────────────────────────────────────────────
//   Dots:   1    2    3    4    5    6    7    8
const int DOT_PINS[8] = {18, 19, 21, 22, 23, 25, 26, 27};

static const uint32_t BAUD_RATE      = 115200;
static const uint32_t SERIAL_WAIT_MS = 500;
static uint32_t       charDelayMs    = 1000;

// ── TCP server / client ──────────────────────────────────────────────────────
WiFiServer tcpServer(TCP_PORT);
WiFiClient tcpClient;
bool       wifiConnected = false;

// ── Input buffers ─────────────────────────────────────────────────────────────
String     serialBuf;
String     tcpBuf;
static const size_t INPUT_MAX = 256;

// ── Braille lookup table ─────────────────────────────────────────────────────
// Bit positions: bit0=dot1  bit1=dot2 ... bit7=dot8
// Dot 7 (0x40) = capital indicator, Dot 8 (0x80) = number indicator.
// Unknown characters fall through to 0xFF (all dots on).

struct BrailleEntry { char ch; uint8_t dots; };

static const BrailleEntry BRAILLE_MAP[] = {
  // Lowercase
  {'a',0x01},{'b',0x03},{'c',0x09},{'d',0x19},{'e',0x11},
  {'f',0x0B},{'g',0x1B},{'h',0x13},{'i',0x0A},{'j',0x1A},
  {'k',0x05},{'l',0x07},{'m',0x0D},{'n',0x1D},{'o',0x15},
  {'p',0x0F},{'q',0x1F},{'r',0x17},{'s',0x0E},{'t',0x1E},
  {'u',0x25},{'v',0x27},{'w',0x3A},{'x',0x2D},{'y',0x3D},{'z',0x35},
  // Uppercase (same braille + dot 7)
  {'A',0x01|0x40},{'B',0x03|0x40},{'C',0x09|0x40},{'D',0x19|0x40},{'E',0x11|0x40},
  {'F',0x0B|0x40},{'G',0x1B|0x40},{'H',0x13|0x40},{'I',0x0A|0x40},{'J',0x1A|0x40},
  {'K',0x05|0x40},{'L',0x07|0x40},{'M',0x0D|0x40},{'N',0x1D|0x40},{'O',0x15|0x40},
  {'P',0x0F|0x40},{'Q',0x1F|0x40},{'R',0x17|0x40},{'S',0x0E|0x40},{'T',0x1E|0x40},
  {'U',0x25|0x40},{'V',0x27|0x40},{'W',0x3A|0x40},{'X',0x2D|0x40},{'Y',0x3D|0x40},
  {'Z',0x35|0x40},
  // Digits (same braille as a-j + dot 8)
  {'1',0x01|0x80},{'2',0x03|0x80},{'3',0x09|0x80},{'4',0x19|0x80},{'5',0x11|0x80},
  {'6',0x0B|0x80},{'7',0x1B|0x80},{'8',0x13|0x80},{'9',0x0A|0x80},{'0',0x1A|0x80},
  // Punctuation & space
  {' ',0x00},
  {',',0x02},{';',0x06},{':',0x12},{'.',0x32},{'?',0x26},
  {'!',0x16},{'-',0x24},{'\'',0x04},{'"',0x36},{'(',0x13},{')',0x2C},
};

static const int BRAILLE_MAP_LEN =
    (int)(sizeof(BRAILLE_MAP) / sizeof(BRAILLE_MAP[0]));

// ── LED helpers ──────────────────────────────────────────────────────────────

void clearAll() {
  for (int i = 0; i < 8; i++) digitalWrite(DOT_PINS[i], LOW);
}

void showPattern(uint8_t dots) {
  for (int i = 0; i < 8; i++)
    digitalWrite(DOT_PINS[i], (dots >> i) & 1 ? HIGH : LOW);
}

uint8_t lookupChar(char c) {
  for (int i = 0; i < BRAILLE_MAP_LEN; i++)
    if (BRAILLE_MAP[i].ch == c) return BRAILLE_MAP[i].dots;
  return 0xFF;
}

void sweepDots() {
  clearAll();
  for (int d = 0; d < 8; d++) {
    digitalWrite(DOT_PINS[d], HIGH);
    delay(150);
    digitalWrite(DOT_PINS[d], LOW);
    delay(60);
  }
  for (int i = 0; i < 8; i++) digitalWrite(DOT_PINS[i], HIGH);
  delay(400);
  clearAll();
}

// ── Reply helper — sends to Serial and active TCP client ─────────────────────

void sendReply(const String& msg) {
  Serial.println(msg);
  if (tcpClient && tcpClient.connected()) {
    tcpClient.println(msg);
  }
}

// ── TEXT command ─────────────────────────────────────────────────────────────

void displayText(const String& text) {
  sendReply("DISPLAYING:" + text);

  for (int idx = 0; idx < (int)text.length(); idx++) {
    char    c    = text[idx];
    uint8_t dots = lookupChar(c);
    showPattern(dots);

    String dotBin = "";
    for (int b = 7; b >= 0; b--) dotBin += String((dots >> b) & 1);
    sendReply(String("CHAR:") + c + "=DOTS_BIN:" + dotBin);

    delay(charDelayMs);
  }

  clearAll();
  sendReply("ACK:TEXT_DONE");
}

// ── DOTS command ─────────────────────────────────────────────────────────────

void activateDotsFromString(const String& dotsStr) {
  uint8_t pattern = 0;
  int startIdx = 0;

  while (startIdx < (int)dotsStr.length()) {
    int comma = dotsStr.indexOf(',', startIdx);
    String part = (comma < 0) ? dotsStr.substring(startIdx)
                               : dotsStr.substring(startIdx, comma);
    part.trim();
    if (part.length() > 0) {
      int n = part.toInt();
      if (n >= 1 && n <= 8) pattern |= (uint8_t)(1 << (n - 1));
    }
    if (comma < 0) break;
    startIdx = comma + 1;
  }

  showPattern(pattern);
}

// ── Command dispatcher ───────────────────────────────────────────────────────

void processLine(const String& lineIn) {
  String msg = lineIn;
  msg.trim();
  if (msg.length() == 0) return;

  if (msg.equalsIgnoreCase("PING")) {
    sendReply("PONG");

  } else if (msg.equalsIgnoreCase("TEST")) {
    sweepDots();
    sendReply("ACK:TEST");

  } else if (msg.equalsIgnoreCase("HELP")) {
    sendReply("CMDS: TEXT:<str> | DELAY:<ms> | DOTS:<1..8,...> | DOTS:NONE | TEST | PING | HELP");

  } else if (msg.startsWith("DELAY:")) {
    int ms = msg.substring(6).toInt();
    if (ms > 0) {
      charDelayMs = (uint32_t)ms;
      sendReply("ACK:DELAY:" + String(charDelayMs));
    } else {
      sendReply("ERROR:Invalid delay value");
    }

  } else if (msg.startsWith("TEXT:")) {
    displayText(msg.substring(5));

  } else if (msg.startsWith("DOTS:")) {
    String dotsStr = msg.substring(5);
    dotsStr.trim();
    if (dotsStr.equalsIgnoreCase("NONE") || dotsStr.length() == 0) {
      clearAll();
      sendReply("ACK:CLEARED");
    } else {
      activateDotsFromString(dotsStr);
      sendReply("ACK:DOTS:" + dotsStr);
    }

  } else {
    sendReply("ERROR:Unknown command — send HELP for list");
  }
}

// ── Arduino entry points ─────────────────────────────────────────────────────

void setup() {
  Serial.begin(BAUD_RATE);
  delay(SERIAL_WAIT_MS);
  Serial.println("BOOT:ESP32 Braille starting");

  for (int i = 0; i < 8; i++) {
    pinMode(DOT_PINS[i], OUTPUT);
    digitalWrite(DOT_PINS[i], LOW);
  }

  // Connect to Wi-Fi
  Serial.print("WIFI:Connecting SSID=");
  Serial.println(WIFI_SSID);
  WiFi.mode(WIFI_STA);
  WiFi.begin(WIFI_SSID, WIFI_PASS);

  uint32_t connectStart = millis();
  uint32_t lastLog      = 0;
  while (WiFi.status() != WL_CONNECTED &&
         (millis() - connectStart) < WIFI_CONNECT_TIMEOUT_MS) {
    delay(200);
    if ((millis() - lastLog) >= WIFI_RETRY_LOG_MS) {
      lastLog = millis();
      Serial.print("WIFI:Still connecting, status=");
      Serial.println(WiFi.status());
    }
  }

  wifiConnected = (WiFi.status() == WL_CONNECTED);
  if (wifiConnected) {
    Serial.print("WIFI:Connected IP=");
    Serial.println(WiFi.localIP());
    tcpServer.begin();
    Serial.print("WIFI:TCP server on port ");
    Serial.println(TCP_PORT);
  } else {
    Serial.println("WIFI:Timeout — continuing in serial-only mode");
  }

  Serial.println("READY:ESP32 Braille 8-LED Text Input");
  Serial.flush();

  sweepDots();
  Serial.println("ACK:STARTUP_SWEEP_DONE");
}

void loop() {
  // Accept a new TCP client whenever none is connected
  if (wifiConnected && (!tcpClient || !tcpClient.connected())) {
    tcpClient = tcpServer.available();
    if (tcpClient) {
      Serial.println("WIFI:Client connected");
      tcpClient.println("READY:ESP32 Braille 8-LED Text Input");
    }
  }

  // Read from Serial
  while (Serial.available() > 0) {
    char c = static_cast<char>(Serial.read());
    if (c == '\n') {
      processLine(serialBuf);
      serialBuf = "";
    } else if (c != '\r') {
      if (serialBuf.length() < INPUT_MAX) serialBuf += c;
    }
  }

  // Read from TCP client
  if (wifiConnected && tcpClient && tcpClient.connected()) {
    while (tcpClient.available() > 0) {
      char c = static_cast<char>(tcpClient.read());
      if (c == '\n') {
        processLine(tcpBuf);
        tcpBuf = "";
      } else if (c != '\r') {
        if (tcpBuf.length() < INPUT_MAX) tcpBuf += c;
      }
    }
  }
}

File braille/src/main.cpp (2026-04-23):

#include <Arduino.h>
#include "BrailleCell.h"

BrailleCell cell;

// Hardware mode:
// - false: direct pin mode (single tile)
// - true: chained SN74HC595 mode (multiple tiles)
const bool USE_SHIFT_REGISTER = true;

// Direct pin mode mapping: index = bit position in pattern byte
const int DOT_PINS[8] = {2, 3, 4, 8, 5, 6, 7, 9};

// SN74HC595 pin configuration and tile count
const uint8_t SR_DATA_PIN = 11;
const uint8_t SR_CLOCK_PIN = 12;
const uint8_t SR_LATCH_PIN = 8;
const uint8_t TILE_COUNT = 4;
const uint8_t DOT_CHIP_COUNT = 6; // 6-dot Braille: one chip per dot line
const uint8_t DOT_BIT_INDEX[6] = {0, 1, 2, 4, 5, 6};

uint8_t tilePatterns[TILE_COUNT];
char inputBuffer[96];
int bufferIndex = 0;

void writeDotPlaneFrame(const uint8_t* patterns, uint8_t count) {
  uint8_t dotPlanes[DOT_CHIP_COUNT];
  memset(dotPlanes, 0, sizeof(dotPlanes));

  // Convert tile-major patterns into dot-major bytes:
  // each chip byte uses bit N to represent tile N.
  for (uint8_t tile = 0; tile < count && tile < 8; tile++) {
    uint8_t pattern = patterns[tile];
    for (uint8_t dot = 0; dot < DOT_CHIP_COUNT; dot++) {
      if (pattern & (1u << DOT_BIT_INDEX[dot])) {
        dotPlanes[dot] |= (1u << tile);
      }
    }
  }

  digitalWrite(SR_LATCH_PIN, LOW);
  for (int chip = DOT_CHIP_COUNT - 1; chip >= 0; chip--) {
    shiftOut(SR_DATA_PIN, SR_CLOCK_PIN, MSBFIRST, dotPlanes[chip]);
  }
  digitalWrite(SR_LATCH_PIN, HIGH);
}

bool parseFrameCommand(const char* cmd) {
  // Command format: FRAME:XX,YY,ZZ,... one byte per tile
  if (strncmp(cmd, "FRAME:", 6) != 0) return false;

  memset(tilePatterns, 0, sizeof(tilePatterns));
  const char* p = cmd + 6;
  uint8_t tile = 0;

  while (*p && tile < TILE_COUNT) {
    char* endPtr = nullptr;
    unsigned long value = strtoul(p, &endPtr, 16);
    if (endPtr == p || value > 0xFF) {
      Serial.println("ERR:bad frame byte");
      return true;
    }
    tilePatterns[tile++] = (uint8_t)value;

    if (*endPtr == ',') {
      p = endPtr + 1;
      continue;
    }
    if (*endPtr == '\0') {
      break;
    }

    Serial.println("ERR:bad frame format");
    return true;
  }

  writeDotPlaneFrame(tilePatterns, TILE_COUNT);
  Serial.println("OK");
  return true;
}

void processCommand(const char* cmd) {
  if (USE_SHIFT_REGISTER && parseFrameCommand(cmd)) {
    return;
  }

  if (cmd[0] == 'P' && cmd[1] == ':') {
    // Pattern command: "P:XX" (tile 0) where XX is 2-digit hex
    uint8_t pattern = (uint8_t)strtoul(cmd + 2, NULL, 16);
    tilePatterns[0] = pattern;
    if (USE_SHIFT_REGISTER) {
      writeDotPlaneFrame(tilePatterns, TILE_COUNT);
    } else {
      cell.setPattern(pattern);
    }
    cell.printVisualization(pattern);
    Serial.println("OK");
  
  } else if (cmd[0] == 'T' && cmd[1] == ':') {
    // Tile command: "T:<tile>:<hex>" e.g. T:2:3F
    const char* firstColon = strchr(cmd, ':');
    if (!firstColon) {
      Serial.println("ERR:bad tile cmd");
      return;
    }
    const char* secondColon = strchr(firstColon + 1, ':');
    if (!secondColon) {
      Serial.println("ERR:bad tile cmd");
      return;
    }

    int tileIndex = atoi(firstColon + 1);
    uint8_t pattern = (uint8_t)strtoul(secondColon + 1, NULL, 16);
    uint8_t maxTiles = USE_SHIFT_REGISTER ? TILE_COUNT : cell.getTileCount();
    if (tileIndex < 0 || tileIndex >= maxTiles) {
      Serial.println("ERR:tile out of range");
      return;
    }

    tilePatterns[tileIndex] = pattern;
    if (USE_SHIFT_REGISTER) {
      writeDotPlaneFrame(tilePatterns, TILE_COUNT);
    } else {
      cell.setPattern((uint8_t)tileIndex, pattern);
    }
    Serial.println("OK");

  } else if (strcmp(cmd, "CLEAR") == 0) {
    memset(tilePatterns, 0, sizeof(tilePatterns));
    if (USE_SHIFT_REGISTER) {
      writeDotPlaneFrame(tilePatterns, TILE_COUNT);
    } else {
      for (uint8_t i = 0; i < cell.getTileCount(); i++) {
        cell.setPattern(i, 0x00);
      }
    }
    Serial.println("OK");

  } else if (strcmp(cmd, "PING") == 0) {
    Serial.println("PONG");

  } else if (strcmp(cmd, "TEST") == 0) {
    // Sweep each LED one at a time, then all on, then clear
    for (int i = 0; i < 8; i++) {
      cell.setPattern(1 << i);
      delay(150);
    }
    cell.setPattern(0xFF);
    delay(400);
    cell.clear();
    Serial.println("OK");

  } else {
    Serial.print("ERR:unknown cmd '");
    Serial.print(cmd);
    Serial.println("'");
  }
}

void setup() {
  Serial.begin(115200);
  memset(tilePatterns, 0, sizeof(tilePatterns));
  if (USE_SHIFT_REGISTER) {
    pinMode(SR_DATA_PIN, OUTPUT);
    pinMode(SR_CLOCK_PIN, OUTPUT);
    pinMode(SR_LATCH_PIN, OUTPUT);
    digitalWrite(SR_DATA_PIN, LOW);
    digitalWrite(SR_CLOCK_PIN, LOW);
    digitalWrite(SR_LATCH_PIN, HIGH);
    writeDotPlaneFrame(tilePatterns, TILE_COUNT);
  } else {
    cell.begin(DOT_PINS);
  }

  delay(500);
  Serial.println("BRAILLE_LED_READY");
  Serial.print("TILES:");
  Serial.println(USE_SHIFT_REGISTER ? TILE_COUNT : cell.getTileCount());
}

void loop() {
  while (Serial.available() > 0) {
    char c = Serial.read();

    if (c == '\r') continue;

    if (c == '\n') {
      inputBuffer[bufferIndex] = '\0';
      if (bufferIndex > 0) {
        processCommand(inputBuffer);
      }
      bufferIndex = 0;
    } else if (bufferIndex < (int)sizeof(inputBuffer) - 2) {
      inputBuffer[bufferIndex++] = c;
    }
  }
}

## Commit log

2025-09-23 Power System
    [BrailleCellController.kicad_pcb, BrailleCellController.kicad_sch, BrailleCellDevelopementBoard.kicad_pcb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]
2025-09-25 minor stuff
    [BrailleCellDevelopementBoard.kicad_pcb, BrailleCellDevelopementBoard.kicad_sch, MCU.kicad_sch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]
2025-10-01 cell shifter routed
    [BrailleCellController.kicad_pcb, BrailleCellController.kicad_sch, BrailleCellDevelopementBoard.kicad_sch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]
2025-10-01 Revert "Delete electrical directory for better gitignore"
    This reverts commit 181b4a21364ede14b701790e8bdf27dabea5567c.
    [BrailleCell.kicad_pcb, BrailleCell.kicad_sch, BrailleCellController.kicad_pcb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]
2025-10-01 Revert "Delete electrical directory"
    This reverts commit 27c4fd279335de581d558488b3912bec10442990.
    [BrailleCell.kicad_pcb, BrailleCell.kicad_sch, BrailleCellController.kicad_pcb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]
2025-10-01 ignore bad files
    [BrailleCell.kicad_pcb, BrailleCell.kicad_sch, BrailleCellController.kicad_pcb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]
2025-11-14 library fix
    [BrailleCell-B_Cu.gbr, BrailleCell-B_Mask.gbr, BrailleCell-B_Paste.gbr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]
2025-11-17 modified library to arduino core library
2025-11-18 Update BrailleConverter.cpp
    modified to be able to fit in the arduino uno
2025-11-18 Update BrailleConverter.h
    edited to allow for fitting into arduino uno
2025-11-18 Create brailledemo
    serial to control signal IO with full braille conversion for arduino uno
2026-02-10 Add OCR functionality and UI buttons for OCR
2026-03-04 Implement open and save text file features
    Added functionality to open and save text files in the application, including UTF-8 BOM handling.
2026-03-06 Add files via upload
    flyback and mosfet
    [uno_hat_dev.kicad_pcb, uno_hat_dev.kicad_sch]
2026-03-07 schematic done
    [uno_hat_dev.kicad_sch]
2026-03-07 started layout
    [uno_hat_dev.kicad_pcb, uno_hat_dev.kicad_sch]
2026-03-23 layout in (1)
    [uno_hat_dev (1).kicad_pcb]
2026-03-31 ECE day demo board added
    [demo_board.kicad_pcb, demo_board.kicad_sch, dotdriver.kicad_sch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]
2026-03-31 Enhance Python integration and file dialog filters
    Updated file filters for open dialog and improved Python integration for Arduino connection. Enhanced error handling and added Python document extraction functionality.
2026-03-31 Updated layout and board shape determined
    [demo_board.kicad_pcb, demo_board.kicad_sch, dotdriver.kicad_sch]
2026-04-03 placement done
    [demo_board.kicad_pcb, demo_board.kicad_sch]
2026-04-05 initial layout of dev
    [demo_board.kicad_pcb, demo_board.kicad_sch, dotdriver.kicad_sch]
2026-04-05 Add shorthand Braille conversion helpers
    This file provides functions to convert text into shorthand Braille, including common contractions and formatting for terminal output.
    [shorthand_braille.py]
2026-04-05 Add desktop UI for document-to-Braille conversion
    This file implements a desktop UI for converting documents to Braille, featuring an Open/Save/Edit/Convert flow. It connects to existing extraction and Braille conversion systems.
2026-04-07 Add to_shorthand_patterns function
    Implement function to convert text to shorthand Braille cell patterns.
    [shorthand_braille.py]
2026-04-09 esp32 wifi conversion
2026-04-10 layout finished
    [demo_board.kicad_pcb, dotdriver.kicad_sch]
2026-04-11 led board
    [demo_board.kicad_pcb, lightboard.kicad_pcb, lightboard.kicad_sch]
2026-04-12 Enhance driver with shorthand and PDF support
    Added support for shorthand braille and PDF text extraction.
2026-04-17 ordered boards
    [demo_board-B_Cu.gbr, demo_board-B_Mask.gbr, demo_board-B_Paste.gbr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]
2026-04-23 Add WiFi TCP to ESP32 firmware and phone-first web UI
    - esp32_braille_text_input.ino: merge WiFi TCP server (port 3333) from
    arduino_8dot_braille sketch; all commands now work over both Serial
    and TCP; falls back to serial-only if WiFi times out
    - app.py: harden _write() to broadcast disconnect + stop send worker on
    TCP failure; add /api/config endpoint; add ACCESS_CODE passcode gate
    on /api/send; validate text length (max 200) and strip control chars
    - index.html: default to WiFi TCP mode; add access-code modal with
    sessionStorage; handle 403 on send; larger touch targets for phones
    - start.sh: one-command launcher that prints the local IP for phones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
    [app.py, esp32_braille_text_input.ino]
2026-04-27 Add queued multi-user send flow for phone web UI.
    This updates the Flask and frontend flow to process submissions in FIFO order with live queue visibility, and adds a runbook/test checklist to finalize deployment verification.
    Made-with: Cursor
